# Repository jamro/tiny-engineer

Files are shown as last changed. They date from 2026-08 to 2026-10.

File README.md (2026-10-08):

# Tiny Engineer

> Give your AI coding agent a body.

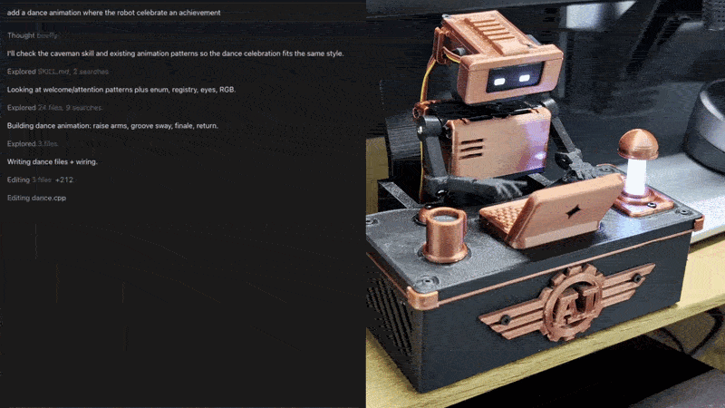
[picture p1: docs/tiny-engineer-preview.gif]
Tiny Engineer demo


**[Watch the demo](https://youtu.be/RX_QRxdXMjg)** · [Build your own](#build-your-own) · [Community builds](#community-builds) · [How it works](#how-it-works)

A small robot on your desk. It moves, changes its face, and rings a bell as your coding AI agent works.

| Your agent… | The robot… |
| --- | --- |
| Reads files | Looks around |
| Writes code | Types |
| Thinks or waits | Looks up |
| Finishes the task | Rings the bell |

Open source. Print the body, plug the ESP32, servos, OLED, and speaker into the [main control board](docs/hardware/main-control-board.md), flash it, and it joins your Wi-Fi.

**Works with** Claude Code · Cursor · Antigravity — via [`npx -y tiny-engineer setup`](docs/integration.md) — or Codex, Windsurf, and any script that can POST ([integration guide](docs/integration.md) · [HTTP API](docs/api.md)), including speech through [`POST /play`](docs/api.md#post-play).

## Build your own

| | |
| --- | --- |
| **Parts (electronics + 5× SG90 Servos)** | [shopping list](docs/shopping.md): [main control board](docs/hardware/order-main-control-board.md) plus ESP32, servos, OLED, and speaker |
| **Also needed** | 3D printer + filament, or [order prints](docs/3d/order-parts.md); M2 screws; **5 V / ≥2 A** USB supply |
| **Tools** | Plug in the ESP32, servos, OLED, and speaker on the [main control board](docs/hardware/main-control-board.md). Want to add extra modules? [advanced wiring](docs/hardware/wiring.md) |
| **Difficulty** | **Medium** - fair first hardware project for a software engineer, not a one-LED kit. Optional primer: [From Code to Circuits](docs/hardware-for-software-engineers/README.md) |

Main control board (https://github.com/jamro/tiny-engineer/discussions/50)

The default build uses the open-source main control board. Order it from any fab ([how to order](docs/hardware/order-main-control-board.md) · [KiCad](hardware/boards/main-control-board/)). 

If a ~$15–20 assembled board like this would be useful to you, [Vote here 👍 →](https://github.com/jamro/tiny-engineer/discussions/50) → I’m using the interest to decide whether it’s worth developing further.

**Print → Connect → Flash → Assemble** - step-by-step: **[Getting started](docs/getting-started.md)**.

## Community builds

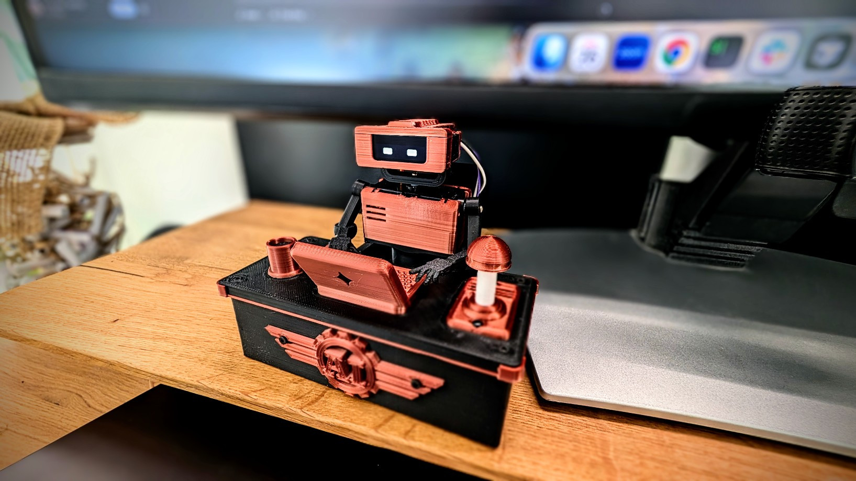
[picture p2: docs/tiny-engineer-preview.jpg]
Built Tiny Engineer


Finished builds, mods, and desk setups live in **[Show and tell](https://github.com/jamro/tiny-engineer/discussions/categories/show-and-tell)** on GitHub Discussions - browse what others made and post photos of yours.

**Built one? [Share in Show and tell →](https://github.com/jamro/tiny-engineer/discussions/categories/show-and-tell)**

## Roadmap

What we are building toward:

- **More agent integrations** - one-command hooks for more IDEs and CLIs
- **Simplified build process** - easier assembly and setup for quicker builds
- **New characters / bodies** - alternate shells and mods
- **Multi-agent desk** - more than one tiny teammate

**[Star Tiny Engineer](https://github.com/jamro/tiny-engineer)** to follow the build.

## How it works

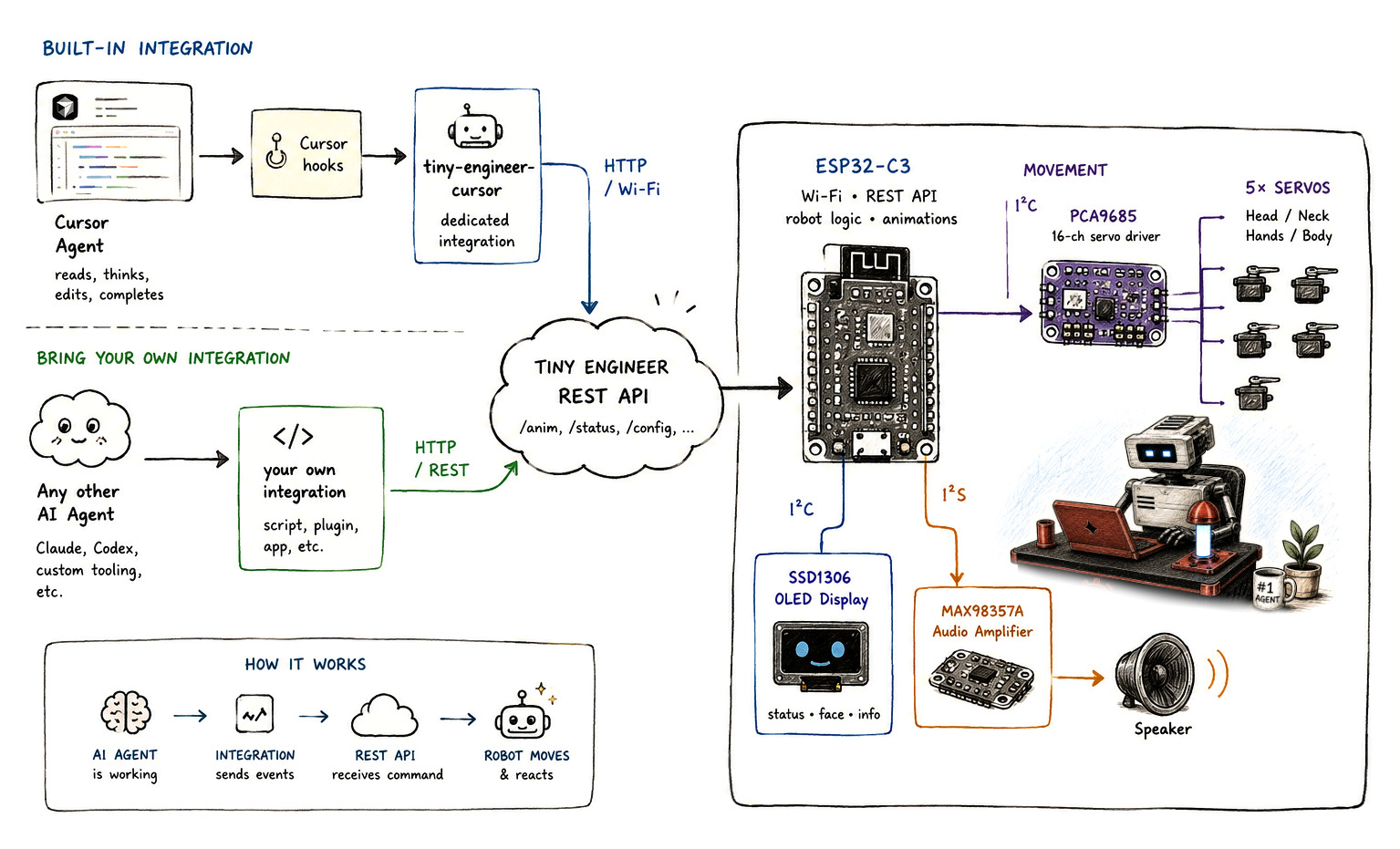
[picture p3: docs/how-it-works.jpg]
How Tiny Engineer works


Your agent (or a hook script) sends poses over HTTP. The **ESP32-C3** is a small Wi-Fi computer on the robot — one chip that runs the program, joins your network, hosts REST API, and drives the servos, the face, and the speaker.

**Clients**

- **Default** — [`npx -y tiny-engineer`](https://www.npmjs.com/package/tiny-engineer) (`setup` / `hook`) for Cursor, Claude Code, Antigravity → Wi-Fi
- **Advanced** — any tool that can `POST` to `/anim` ([HTTP API](docs/api.md))

Details: [Integrations](docs/integration.md) · [HTTP API](docs/api.md) · [Cursor hooks](docs/hooks.md)

## Documentation

| You want to… | Start here |
| --- | --- |
| Build the robot | [Getting started](docs/getting-started.md) |
| Buy parts | [Shopping list](docs/shopping.md) |
| Flash the board | **[Web flash](https://jamro.github.io/tiny-engineer/flash/)** · [Flash](docs/flash.md) |
| Assemble the prints | [Assembly](docs/3d/assembly.md) |
| Print the parts | [3D models](3d_models/README.md) |
| Hook up an agent | [Integrations](docs/integration.md) |
| Call the HTTP API | [API](docs/api.md) |
| Anything else | [Docs index](docs/README.md) |

Print it, connect it, change the CAD, or hook up another agent. Issues and PRs welcome - especially new integrations. [CONTRIBUTING.md](CONTRIBUTING.md) · [SECURITY.md](SECURITY.md) · [CODE_OF_CONDUCT.md](CODE_OF_CONDUCT.md)

## License

- **Software** (firmware, integrations, scripts, documentation) — [MIT](LICENSE)
- **Hardware designs** (CAD source and printables in [`3d_models/`](3d_models/) and under [`mods/*/3d_models/`](mods/); KiCad PCBs in [`hardware/`](hardware/)) — [CERN-OHL-S-2.0](3d_models/LICENSE)

See [LICENSING.md](LICENSING.md) for scope and effective date. The **Tiny Engineer** name and logo are not licensed - see [TRADEMARK.md](TRADEMARK.md).

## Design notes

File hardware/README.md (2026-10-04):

# Hardware (PCB)

KiCad PCB projects for Tiny Engineer. Builders: the main control board is the default electronics path — [shopping](../docs/shopping.md) and [connect guide](../docs/hardware/main-control-board.md). Breakout modules are an advanced path for extra hardware the board does not support — [wiring](../docs/hardware/wiring.md).

Boards live under `boards/<board-name>/`. Prefer the same name for the directory and the KiCad project.

| Board | Role |
| --- | --- |
| [`main-control-board`](boards/main-control-board/) | Main board: PCA9685, MAX98357A, and USB-C on the board; ESP32-C3-Zero plugs into two sockets |

Contribution rules, KiCad version, what to commit, ERC/DRC, and PR expectations: [docs/pcb.md](../docs/pcb.md). Pre-PR checklist: [docs/pcb.md#checklist](../docs/pcb.md#checklist). Critical net checklist: [docs/pcb.md#expected-netsyml](../docs/pcb.md#expected-netsyml). Local/CI checks: `python3 scripts/check_pcb.py` (KiCad 10) — [docs/testing.md](../docs/testing.md).

This tree is KiCad source only. Robot electrical reference (pinout, wiring, BOM) is [`docs/hardware/`](../docs/hardware/README.md). Firmware drivers are `src/hardware/`.

## License

Board sources in `boards/` are [CERN-OHL-S-2.0](LICENSE). See [NOTICE](NOTICE) for copyright, Source Location, and product notice requirements.

This README is software documentation and remains under the MIT License — [LICENSING.md](../LICENSING.md).

The **Tiny Engineer** name and logo are not licensed — [TRADEMARK.md](../TRADEMARK.md).

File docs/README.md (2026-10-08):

# Docs index

Pick a path. Depth lives in the linked pages.

### Building the robot

| You want to… | Start here |
| --- | --- |
| **Build from scratch** (canonical checklist) | [getting-started.md](getting-started.md) |
| **Buy parts** (main control board + cart) | [shopping.md](shopping.md) |
| **Bridge into hardware/electronics** (software engineer background) | [hardware-for-software-engineers/README.md](hardware-for-software-engineers/README.md) — optional parallel reading; safety card lives on the checklist |
| **Assemble printed parts** (mechanical procedure) | [3d/assembly.md](3d/assembly.md) |
| **Flash firmware** | **[Web flash](https://jamro.github.io/tiny-engineer/flash/)** (default) · [flash.md](flash.md) (PlatformIO / mods / OTA) |
| **Electronics** (main control board) | [shopping.md](shopping.md) → [hardware/main-control-board.md](hardware/main-control-board.md) → [hardware/README.md](hardware/README.md) |
| **Extra modules** (advanced breakouts) | [shopping.md](shopping.md#advanced-extra-modules) → [hardware/wiring.md](hardware/wiring.md) → [3d/assembly-modular.md](3d/assembly-modular.md) |
| **Print / parts inventory** | [../3d_models/README.md](../3d_models/README.md) |
| **Order printed parts** (no 3D printer) | [3d/order-parts.md](3d/order-parts.md) |
| **Order main control board** (PCB / PCBA) | [hardware/order-main-control-board.md](hardware/order-main-control-board.md) |
| **Adapt CAD to a different servo** | [3d/parametric-design.md](3d/parametric-design.md) |
| **Add a new CAD / printable part** | [3d/adding-parts.md](3d/adding-parts.md) |
| **Optional mods** | [../mods/README.md](../mods/README.md) |
| **Use with an agent** (robot already on Wi-Fi) | [integration.md](integration.md) (`tiny-engineer` CLI or REST) · Cursor: [hooks.md](hooks.md) |

### Reference and contribute

| You want to… | Start here |
| --- | --- |
| **Contribute a PCB** (KiCad) | [pcb.md](pcb.md) → [`hardware/`](../hardware/README.md) |
| **HTTP API / settings** | [api.md](api.md); add a setting: [settings.md](settings.md) |
| **CLI setup / REST for any IDE** | [integration.md](integration.md) |
| **Publish npm CLI** (`tiny-engineer`) | [cli-release.md](cli-release.md) |
| **Firmware / package tests** | [testing.md](testing.md) |
| **AI coding agents (repo rules)** | [AGENTS.md](../AGENTS.md) |
| **Contribute / report a vuln** | [CONTRIBUTING.md](../CONTRIBUTING.md); [SECURITY.md](../SECURITY.md) |
| **Share a finished build** | [Show and tell](https://github.com/jamro/tiny-engineer/discussions/categories/show-and-tell) — [how to post](../CONTRIBUTING.md#share-your-build) |

Also: [robot-movement.md](robot-movement.md) (servo axes and safe ranges); optional [macos-lock-unlock.md](macos-lock-unlock.md) (sleep/wake on Mac screen lock).

**Source of truth:** pin constants in firmware (`include/pins.h`); electrical detail in `docs/hardware/`; HTTP shapes in [api.md](api.md). Overall build order: [getting-started.md](getting-started.md).

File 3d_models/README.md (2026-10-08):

# 3D models

Printable parts and source CAD for the Tiny Engineer desk robot.

## Source CAD (edit / resize)

The full assembly — all components composed — lives in [`cad/TinyEngineer.f3d`](cad/TinyEngineer.f3d) (Autodesk Fusion). Open that file to adjust the model or adapt it to different hardware sizing (e.g. different servos). Parametric servo sizes and the Fusion add-in: [docs/3d/parametric-design.md](../docs/3d/parametric-design.md).

**Adding a new part** (parametric rules, timeline, `PRINT_LAYOUT`, Servo Configurator, export, optional mods): [docs/3d/adding-parts.md](../docs/3d/adding-parts.md). Optional / community mods: [`mods/`](../mods/).

## Printables

Individual parts are exported under [`parts/{servo_id}/`](parts/). Match the folder to the servos you bought ([which servo](../docs/shopping.md)). `stl/` next to `3mf/` is the same mesh in binary STL. `step/` next to those is CAD interchange (BRep STEP), not a printable mesh for a home slicer.

Two ways to get the mechanical set (same place in the build path):

- **Print yourself** — use the **`.3mf` files in `parts/sg90/3mf/`**, **`parts/fs0307/3mf/`**, **`parts/es9051/3mf/`**, or **`parts/hd1370a/3mf/`**. Ready to print in an orientation that does not need supports. **PLA** or **PETG**. Start with [Print first](#print-first).
- **No printer?** — order the aggregated sets from a third-party service: [order printed parts](../docs/3d/order-parts.md). Orders are at your own risk; fit can vary by provider and design revision.

### Print first

**Home printers only.** Print these two small testers from that folder **before** the rest of the set. Do not print the full robot until both fit. Skip this step when ordering from a service (testers alone are rarely worth the min fee + shipping).

1. **`ServoSizingTester.3mf`** — seat a real servo; do not force it. The body should slide, tabs sit, holes line up, and the shaft should have clearance. Tight or loose → sand/ream, or adjust servo CAD params ([parametric design](../docs/3d/parametric-design.md)).
2. **`ScrewSizingTest.3mf`** — M2 screw pilot-hole tolerance. Each hole is marked with its diameter. Drive an M2 screw into each hole and pick the tightest size that still cuts a thread (does not spin freely / slide through). Set Fusion user parameter `screw_thread_diameter` to that marked value, then re-export before printing structural parts. Details: [M2 screw holes](../docs/3d/parametric-design.md#m2-screw-holes).

Assembly uses **M2 screws** that thread directly into the printed PLA/PETG — no glue, no heat-set inserts. Easy to dismount and modify later. Buyer cart (electronics + screw qty + supply): [docs/shopping.md](../docs/shopping.md). Overall build order: [docs/getting-started.md](../docs/getting-started.md). Mechanical procedure: [docs/3d/assembly.md](../docs/3d/assembly.md). Per-step lengths: [screw list](#screws) below.

### Screws

**Spec:** M2 thread-forming (self-tapping) screws for plastic, **pan-head or button-head** — heads normally sit on the plastic surface. `BottomCover` has recessed head pockets; use heads no larger than **4.0 mm diameter × 2.0 mm high** so the underside rests flat. CAD default pilot is **2.1 mm** (Fusion user parameter `screw_thread_diameter`); if your `ScrewSizingTest` winner differs, re-export at that diameter before printing structural parts. Details: [M2 screw holes](../docs/3d/parametric-design.md#m2-screw-holes).

**One BOM for every servo preset** (`parts/sg90/`, `parts/fs0307/`, `parts/es9051/`, `parts/hd1370a/`, …). Printed parts scale with the servo choice, but the lengths below are the reference list for all of them — including smaller models for smaller servos. Buy quantities: [docs/shopping.md](../docs/shopping.md). Pilots are cut as deep as practical so nearby lengths often work too; if you already have different M2 lengths, test-fit before buying a full set. Per-step placement: [assembly guide](../docs/3d/assembly.md).

**Per robot (qty is source of truth):**

| Item | Qty | Typical use |
| --- | --- | --- |
| M2×4 mm | 8 | Emblem, PCA9685, MAX98357A |
| M2×8 mm | 27 | Hat, Neck↔Head, Chest center (prefer two), Belly↔Chest, LampBase, laptop, mug, Chair↔Desk, elbows, BottomCover ×6 |
| M2×16 mm | 15 | Chest side servos, SeatLeft/Right, DeskTop stack, USB-C, Bell |
| M2 nuts | 6 | Neck captured ×1, USB-C ×4, Bell ×1 |
| Servo bag screws | 5 | Neck shaft, Neck↔Head (robot’s left), Belly shaft, both arms |

Prefer **two** M2×8 for the Neck servo in `Chest`; one at the back is enough if space is tight (buy 27 either way). An M2 assortment covering **M2×4–M2×16** is the easy path.

## Parts

Same filenames in each `parts/{servo_id}/3mf/` folder (and matching `stl/` / `step/`):

| File | Role |
| --- | --- |
| `PartsSetA.3mf` | Aggregated copper-color group for [service orders](../docs/3d/order-parts.md) (home print: use individuals below) |
| `PartsSetB.3mf` | Aggregated black-color group for [service orders](../docs/3d/order-parts.md) (home print: use individuals below) |
| `Head.3mf` | Head (pitch) |
| `Neck.3mf` | Neck (yaw) |
| `ForearmLeft.3mf` | Left forearm / hand |
| `ForearmRight.3mf` | Right forearm / hand |
| `UpperArm.3mf` | Upper arm |
| `Chest.3mf` | Chest / torso |
| `Belly.3mf` | Belly |
| `Chair.3mf` | Chair |
| `SeatLeft.3mf` | Left chair seat |
| `SeatRight.3mf` | Right chair seat |
| `Desk.3mf` | Desk structure |
| `BottomCover.3mf` | Underside cover; six M2×8 (four desk, two chair) |
| `DeskTop.3mf` | Desk top surface |
| `DeskPad.3mf` | Desk pad |
| `LaptopCase.3mf` | Miniature laptop body |
| `LaptopScreen.3mf` | Laptop screen |
| `Bell.3mf` | Service bell |
| `LampBase.3mf` | Desk lamp base |
| `LampCap.3mf` | Lamp cap |
| `LampDiffuser.3mf` | Lamp diffuser |
| `LampButton.3mf` | Lamp button |
| `Mug.3mf` | Mug |
| `Coffee.3mf` | Coffee fill |
| `Hat.3mf` | Hat |
| `ServoSizingTester.3mf` | Servo pocket fit tester |
| `ScrewSizingTest.3mf` | M2 screw pilot-hole diameter tester |
| `AiEmblem.3mf` | AI emblem detail |

## Next steps

Return to the build checklist: [docs/getting-started.md](../docs/getting-started.md) ([§2 Print or order](../docs/getting-started.md#2-print-or-order) done). Connect and flash **before** opening the mechanical guide.

1. Connect, then flash: [docs/hardware/main-control-board.md](../docs/hardware/main-control-board.md), [docs/flash.md](../docs/flash.md). Extra modules: [docs/hardware/wiring.md](../docs/hardware/wiring.md)
2. Assemble in one run: [docs/3d/assembly.md](../docs/3d/assembly.md)
3. Servo axes and safe ranges: [docs/robot-movement.md](../docs/robot-movement.md)
4. Bring-up and failures: [docs/hardware/testing.md](../docs/hardware/testing.md)

## License

CAD source (`.f3d`) in [`cad/`](cad/) and printable parts (`.3mf`) in [`parts/`](parts/) are licensed under [CERN-OHL-S-2.0](LICENSE). See [NOTICE](NOTICE) for copyright, Source Location, and product notice requirements.

Commercial use is allowed. If you modify and distribute Products based on these designs, reciprocal provisions require sharing your Complete Source under the same license. This documentation file is software documentation and remains under the MIT License — see [LICENSING.md](../LICENSING.md).

The **Tiny Engineer** name and logo are not licensed — see [TRADEMARK.md](../TRADEMARK.md).

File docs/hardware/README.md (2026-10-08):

# Tiny Engineer — hardware overview

Canonical hardware reference for the Tiny Engineer robot.

Firmware pin constants live in [`include/pins.h`](../../include/pins.h). The default build is the **main control board** ([main-control-board.md](main-control-board.md)). The advanced path wires separate breakouts ([wiring.md](wiring.md) + drawio) when you add modules the board does not support. Same nets and firmware.

Source of truth: firmware `include/pins.h`, then this `docs/hardware/` set. Modular topology: `docs/wiring/`. PCB connectivity: board `expected-nets.yml` / netlist per [pcb.md](../pcb.md).

| Audience | Use this set for |
| --- | --- |
| Human | Assembly, wiring, power, bring-up, debugging |
| Firmware agent | Pin map, buses, voltages, servo PWM conventions, test sequence |

## Purpose

Small desktop robot with:

- 5 analog micro servos (head, neck, hands, body — [robot-movement.md](../robot-movement.md))
- I2C OLED status display
- I2S speaker for tones and WAV playback
- ESP32-C3 Wi-Fi for HTTP control and AI hooks

Firmware (`src/main.cpp`) is the robot application: Wi-Fi, settings, hardware tests, animations, and the JSON API.

## Hardware architecture

One ESP32-C3 module owns all logic. Servo PWM is offloaded to a PCA9685 so pulse generation does not depend on ESP32 timing. Audio is I2S into a class-D amp. Display and servo driver share one I2C bus. On the default build those chips are on the main control board. The advanced path puts the same chips on breakouts — the diagram is the same either way.

```mermaid
flowchart TB
  USB["USB 5V / GND<br/>as drawn"]

  subgraph p5["5 V power domain"]
    ESP5["ESP32 5V"]
    PCA5["PCA9685 5V"]
    PCAVplus["PCA9685 V+"]
    MAXVIN["MAX98357A Vin"]
    SERVOS["Servo 5V"]
  end

  subgraph p33["3.3 V logic domain"]
    ESP["ESP32-C3-Zero"]
    PCA["PCA9685 VCC"]
    OLED["OLED VCC"]
  end

  USB -->|"5V"| ESP5
  USB -->|"5V"| PCA5
  USB -->|"5V"| MAXVIN
  PCA5 --> PCAVplus
  PCAVplus --> SERVOS
  ESP5 --> ESP
  ESP -->|"3V3"| PCA
  ESP -->|"3V3"| OLED
  ESP -->|"GP0 SDA / GP1 SCL"| PCA
  ESP -->|"GP0 SDA / GP1 SCL"| OLED
  ESP -->|"GP2 BCLK / GP3 LRC / GP4 DIN"| MAXVIN
  PCA -->|"PWM"| SERVOS
```

Speaker **SPK+/SPK-**: [main-control-board.md](main-control-board.md). The modular PNG omits them — [wiring.md](wiring.md#not-on-the-drawing).

| Domain | Voltage | What lives there |
| --- | --- | --- |
| Power rail | **+5V** | USB **5V** → ESP32 **5V**, PCA9685 **5V**, MAX98357A **Vin**; PCA9685 **V+** → servo **5V** |
| Logic | **3V3** | ESP32 GPIO, PCA9685 **VCC**, OLED **VCC**, I2C, I2S |
| Ground | **GND** | Every module — common ground is mandatory |

> [!WARNING]
> Never power the servos from the ESP32 3.3 V regulator.

> [!WARNING]
> MAX98357A SPK- is not ground. Speaker connects between SPK+ and SPK- only.

## Major components

| Role | Main control board (default) | Advanced breakouts | Qty |
| --- | --- | --- | --- |
| Controller | Waveshare ESP32-C3-Zero (plugs into board sockets) | same | 1 |
| Servo PWM | PCA9685 on PCB | Adafruit PCA9685 breakout | 1 |
| Actuators | Analog micro servos — **Tower Pro SG90 recommended**; Feetech FS0307 / EMAX ES9051 compact; PowerHD HD-1370A still supported | same | 5 |
| Audio amp | MAX98357A on PCB | MAX98357A breakout | 1 |
| Speaker | [Adafruit Mini Oval Speaker - 8 Ohm 1 Watt](https://www.adafruit.com/product/3923) | same | 1 |
| Display | [Waveshare 0.91inch OLED Module](https://www.waveshare.com/0.91inch-oled-module.htm) (SSD1306, 128×32, I2C) | same | 1 |
| Robot USB | USB-C on PCB | Adafruit 5993 USB-C breakout | 1 |

Carts: [shopping.md](../shopping.md). Spec detail: [components.md](components.md). Connect: [main-control-board.md](main-control-board.md).

## Communication buses

| Bus | ESP32 pins | Devices |
| --- | --- | --- |
| I2C | GP0/SDA, GP1/SCL (Waveshare OLED **SCL**) | PCA9685 `0x40`, SSD1306 `0x3C` |
| I2S | GP2/BCLK, GP3/LRC, GP4/DIN | MAX98357A |
| Servo PWM | *(none on ESP32)* | PCA9685 channels 0–4 @ 50 Hz |
| USB | Board USB-C (VBUS/GND + D+/D− → GP19/GP18). Advanced path: 5993 — [wiring.md](wiring.md) | Power, flash, serial CDC |

Details: [interfaces.md](interfaces.md), [pinout.md](pinout.md).

## Power architecture

Single nominal **+5V** supply via the main control board USB-C. ESP32 onboard LDO makes **3V3** for logic only. PCA9685 **V+** (servos) is electrically separate from PCA9685 **VCC** (logic). The advanced path brings 5 V in through an Adafruit 5993 — [wiring.md](wiring.md).

Prefer a **5 V / ≥2 A** source with margin. Details: [power.md](power.md).

## Documentation map

| File | Contents |
| --- | --- |
| [../shopping.md](../shopping.md) | Default cart; advanced extra modules |
| [main-control-board.md](main-control-board.md) | Default connect: ESP32, OLED, servos, speaker |
| [order-main-control-board.md](order-main-control-board.md) | Order the PCB / PCBA (any fab; JLCPCB walkthrough) |
| [components.md](components.md) | Inventory, voltages, limits |
| [pinout.md](pinout.md) | GPIO map + allocation rules |
| [wiring.md](wiring.md) | Advanced: breakout harness |
| [../3d/assembly-modular.md](../3d/assembly-modular.md) | Advanced: mount breakouts in the desk |
| [power.md](power.md) | Budget, brownout symptoms, single-USB policy |
| [servos.md](servos.md) | PWM, test limits, safe ranges |
| [interfaces.md](interfaces.md) | I2C / I2S / PWM / USB |
| [testing.md](testing.md) | Bring-up sequence, failures, what to check |

Modular schematic sketch: [`docs/wiring/Tiny Engineer.drawio`](../wiring/Tiny%20Engineer.drawio) / [PNG](../wiring/Tiny%20Engineer.drawio.png). KiCad: [`hardware/boards/`](../../hardware/README.md); contribution rules: [`docs/pcb.md`](../pcb.md).

## Source-of-truth order

1. Repository firmware / `include/pins.h`
2. This `docs/hardware/` set; modular nets also in `docs/wiring/`; PCB nets via board expected-nets / netlist
3. Component datasheets

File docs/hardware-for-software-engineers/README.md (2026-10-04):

# From Code to Circuits: Hardware for Software Engineers

*Learn electronics and physical builds through Tiny Engineer — a desk robot that's fun to finish and honest about real hardware.*

I wrote this because software engineers keep asking how to build Tiny Engineer when they've never touched the hardware side — what's a servo driver, why two voltages, whether they'll destroy the board on first power-on. The build docs tell you *what to connect*; this guide answers the questions behind them.

---

## Goal

**Bring the world of electronics and hardware closer to software engineers** — especially the ones showing up with Tiny Engineer parts and no hardware background.

If you live in code, hardware docs can feel like a foreign API with no types and no stack traces. This guide closes that gap: same systems thinking you already use — buses, power budgets, failure modes — applied to volts, GPIO, and printed plastic. It's the long-form version of answers I give when someone says *"I'm a developer, I just want the robot to work."*

**Why now:** AI makes writing code fast and cheap. Hardware stays tangible, constrained, and extremely satisfying when something on your desk actually moves because *you* wired it.

**Why Tiny Engineer as the example:** one coherent stack (MCU, I2C, I2S, power domains, 3D print, servos) — real enough to teach honest hardware, bounded enough to finish if you stick with it. It also ties back to software via Wi-Fi and HTTP, which helps the mental bridge.

**What you'll get out of it:** read datasheets, schematics, and embedded docs without feeling like an outsider — whether you build this robot or the next board on your bench.

**Honest expectation:** Tiny Engineer was never meant to be an entry-level electronics kit (no single-LED breadboard tutorial). Overall difficulty is **medium**. It can still be your **first hardware project** as a software engineer — if you read alongside the build, smoke-test the main control board on the desk (connect + flash) before closing the shell, and don't treat "first" as "trivial." Harness examples later in this guide are the advanced path for extra modules — [wiring.md](../hardware/wiring.md). See [difficulty by area](#honest-difficulty-by-area) below.

---

I'm a software engineer. I got into hardware and electronics long before Tiny Engineer — out of curiosity, because I find it fun, and because making something *physical* work hits different from shipping another service. I'm not an EE. I've smelled the regret breadboard too; I've also had plenty of projects since then that actually moved and blinked.

Tiny Engineer is one project in that line. I'd recommend this path to any software engineer: learn the basics, wire something on a bench, watch it do a thing you commanded. Especially now, when a servo buzzes because you misaligned a horn — not because a model hallucinated a pin number — you learn something no codegen session replaces.

**What this is:** a bridge into electronics, microcontrollers, power, protocols, and mechanical build craft — taught with software-engineer mental models.

**What this is not:** only a Tiny Engineer assembly manual. When you're ready to build step by step, use [getting-started.md](../getting-started.md) (checklist), [flash.md](../flash.md), and the [hardware reference](../hardware/README.md).

---

## Why Tiny Engineer is the example

Every chapter teaches a **general concept**, then shows **where it lands in this build**. Tiny Engineer gives you real constraints — 3.3 V vs 5 V domains, shared I2C, offloaded servo PWM, print tolerances, antenna keep-out — without throwing you into a parts warehouse with no narrative. Finish the robot if you want the payoff; the vocabulary transfers to other ESP32, Arduino, or IoT projects either way.

It's a good **first hardware project for a software engineer**. It is **not** a good **first project in electronics** in the abstract — compare it to a blinking-LED kit and this is several notches up. This guide exists because those two truths collide constantly in questions from SWEs who want to build the robot anyway.

---

## Honest difficulty by area

Rough levels: **Easy** · **Medium** · **Medium–High** (for someone with no prior hardware builds). Overall build: **Medium**.

| Area | Level | Why |
| --- | --- | --- |
| [Electricity & power domains](01-electricity-and-units.md) | Medium | Two voltage rails, common GND, VCC vs V+ — mistakes fry boards, not just fail tests |
| [Microcontrollers & ESP32](02-microcontrollers-and-esp32.md) | Medium | Wi-Fi MCU, native USB, scarce GPIO, flash/LittleFS — more moving parts than Arduino Uno 101 |
| [Wiring & schematics](03-wiring-craft-and-schematics.md) | Medium–High | Default board is plug-in. The advanced harness is six-ish modules, many nets, classic traps (swapped I2C, speaker on GND) |
| [Buses: I2C, I2S, PWM](04-buses-and-protocols.md) | Medium | Three protocol types in one device; standard hobby stack, but not "one wire one LED" |
| [Servos & mechanical motion](05-servos-and-mechanical-motion.md) | Medium–High | Five joints, horn alignment, mechanical limits, binding/stall — software clamps can't fix physics |
| [3D printing & mechanical build](06-3d-printing-and-mechanical-build.md) | Medium | Many printed parts, tolerances, partial assembly docs; optional Fusion edits add learning curve |
| [Power budgets & safety](07-power-budgets-and-safety.md) | Medium | Real stall currents (~1.3–1.6 A), supply sizing, brownout debugging |
| [Embedded workflow & debug](08-tools-debugging-and-embedded-workflow.md) | Medium *(lower if you live in CLI)* | PlatformIO, serial, bisect bring-up — familiar shape for SWEs, unfamiliar failure modes |
| REST / Wi-Fi / agent hooks | Easy *(for SWEs)* | HTTP you already know — **after** hardware works |

**What makes it medium, not beginner-kit:**
- Multiple ICs on shared buses, not one chip
- Motor power + logic power discipline
- Mechanical assembly with real tolerances
- Debug requires dividing hardware vs software

**What makes it viable as a first SWE hardware project:**
- Documented BOM, wiring, firmware — not a blank breadboard
- Software-shaped affordances: serial logs, HTTP `/test/*`, web UI
- This guide translates concepts into your vocabulary first
- Finish line is motivating (desk robot, not only a blinking LED)

If you've never touched a multimeter, budget extra time on [Ch. 01](01-electricity-and-units.md), [Ch. 07](07-power-budgets-and-safety.md), and bring-up discipline in [Ch. 08](08-tools-debugging-and-embedded-workflow.md). Skipping straight to "assemble everything and flash" (or closing the chest before desk smoke) is how medium projects feel hard.

---

## Who should read this

**Read this if you:**
- Write code for a living and want to build Tiny Engineer (or similar) without a hardware background
- Got the parts or the repo and hit questions the assembly docs don't pause to explain
- Know what HTTP is but not what I2C is
- Can follow a tutorial but want to understand what you're doing
- Are curious about embedded, IoT, or physical computing — even if you've never soldered

**Skip this if you:**
- Already own a multimeter and use words like "pull-up" without Googling
- Have built an ESP32 project before and just need the BOM — go to [shopping.md](../shopping.md) and [getting-started.md](../getting-started.md)

**Don't skip the difficulty section** if this is your first hardware build — [Honest difficulty by area](#honest-difficulty-by-area) sets expectations.

---

## How this fits the rest of the docs

There are three layers. Read them in order when you're learning; jump to the right layer when you know what you need.

```mermaid
flowchart LR
  primer["hardware-for-software-engineers\n(concepts)"]
  build["getting-started.md\n(checklist)"]
  ref["hardware/\n(reference)"]

  primer -->|"understand why"| build
  build -->|"look up details"| ref
```

| Layer | When to use it |
| --- | --- |
| **This guide** | Bridging hardware/electronics concepts from a software background |
| **[getting-started.md](../getting-started.md)** | Canonical build checklist (open leaf docs, return) |
| **[hardware/](../hardware/README.md)** / [flash.md](../flash.md) | Looking up pins, wiring, power, flash, test procedures |

---

## Reading order

**Alongside the checklist** if hardware is new — print while you read; do not finish this guide before [getting-started.md](../getting-started.md):

1. [Electricity and units](01-electricity-and-units.md)
2. [Microcontrollers and ESP32](02-microcontrollers-and-esp32.md)
3. [Wiring craft and schematics](03-wiring-craft-and-schematics.md)
4. [Buses and protocols](04-buses-and-protocols.md)
5. [Servos and mechanical motion](05-servos-and-mechanical-motion.md)
6. [3D printing and mechanical build](06-3d-printing-and-mechanical-build.md)
7. [Power budgets and safety](07-power-budgets-and-safety.md)
8. [Tools, debugging, and embedded workflow](08-tools-debugging-and-embedded-workflow.md)
9. [How it all fits together](09-how-it-all-fits-together.md)

**Shortcuts** — where universal concepts land in this build; jump to one chapter if you only need that topic:

| You need to understand… | Read |
| --- | --- |
| ESP32-C3-Zero, GPIO, USB, antenna | [Ch. 02](02-microcontrollers-and-esp32.md) |
| 3.3 V vs 5 V, LDO, VCC vs V+ | [Ch. 01](01-electricity-and-units.md) + [Ch. 07](07-power-budgets-and-safety.md) |
| I2C (OLED + PCA9685) | [Ch. 04](04-buses-and-protocols.md) |
| I2S (audio) | [Ch. 04](04-buses-and-protocols.md) |
| Servo PWM chain | [Ch. 04](04-buses-and-protocols.md) + [Ch. 05](05-servos-and-mechanical-motion.md) |
| Fusion CAD edits | [Ch. 06](06-3d-printing-and-mechanical-build.md) |
| PLA vs PETG | [Ch. 06](06-3d-printing-and-mechanical-build.md) |

---

## Mini glossary

Terms you'll see everywhere. Each chapter goes deeper. Think of these as hardware concepts translated into software-shaped words.

| Term | One-line meaning |
| --- | --- |
| **MCU** | The chip that runs your firmware — like a tiny server that boots straight into one binary (no OS, no SSH). Here: ESP32-C3 |
| **GPIO** | A pin the firmware can drive or read — hardware I/O endpoints, not USB or Wi-Fi |
| **GND** | Shared **0 V reference** for every module — like agreeing on one clock/time base; without it, nothing can talk reliably |
| **3.3 V / 5 V** | **Signal voltage** (3.3 V, ESP32-safe) vs **power rail** (5 V, servos/amp) — two different numbers; don't mix them up |
| **LDO** | Onboard **5 V → 3.3 V converter** for logic chips — sized for milliamps, not motors |
| **I2C** | Two-wire **request/response bus** — each chip has an address (`0x40`, `0x3C`); ESP32 is the only master |
| **I2S** | **Streaming audio bus** — continuous PCM samples over wires, like a one-way socket, not I2C-style reads |
| **PWM** | A pin toggling on/off on a schedule — servos read **pulse length** inside each cycle as "go to this angle" |
| **Brownout** | Power sags → chip **hard-resets** — feels like a random reboot, often when servos or audio spike current |
| **PCA9685** | **Servo PWM co-processor** — ESP32 sends angles over I2C; this chip generates the precise 50 Hz pulses |

---

## When you're ready to build

You've read enough when you can explain in plain language:

- Why servos don't get power from the ESP32's 3.3 V pin
- What I2C and I2S do on this robot (and that they're different)
- Why there's a separate PCA9685 chip instead of "just PWM in code"
- Where the ceramic antenna is and why you shouldn't bury it in plastic

**Minimum skim before power:** [Ch. 01](01-electricity-and-units.md) and [Ch. 07](07-power-budgets-and-safety.md) (3.3 V vs 5 V, VCC ≠ V+). This guide is **parallel reading**, not a prerequisite. Jump to one chapter from the shortcuts table if you only need that topic.

Then open [getting-started.md](../getting-started.md) and work the checklist (shop → print → connect → flash → assemble → wizard → prove).

**Reference:** [getting-started.md](../getting-started.md) · [hardware/README.md](../hardware/README.md) · [3d_models/README.md](../../3d_models/README.md)

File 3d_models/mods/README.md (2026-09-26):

# Mods

Optional and community CAD mods for Tiny Engineer. Not stock robot parts — those live in [`cad/`](../cad/) and [`parts/`](../parts/).

## Layout

```text
mods/<mod_name>/
  cad/       # Fusion source
  parts/     # Exported meshes (mirror 3d_models/parts/)
  README.md  # recommended: fit notes, which servo folders exported
```

## Workflow

Design, timeline, `PRINT_LAYOUT`, export, and checklist: [docs/3d/adding-parts.md](../../docs/3d/adding-parts.md).

## License

Same as parent [`3d_models/`](../) — [CERN-OHL-S-2.0](../LICENSE). See [NOTICE](../NOTICE).

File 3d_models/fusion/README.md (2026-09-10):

# Fusion add-in

Add-in code lives in [`TinyEngineerTools/`](TinyEngineerTools/). Folder name, `TinyEngineerTools.py`, and `TinyEngineerTools.manifest` must stay the same.

Install, servo parameters, configurator, and export: [docs/3d/parametric-design.md](../../docs/3d/parametric-design.md).

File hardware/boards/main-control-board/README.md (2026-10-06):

# main-control-board

This board drives the robot's servos and speaker. Power and USB data come in on a USB-C connector. The Waveshare ESP32-C3-Zero is not soldered down; it plugs into two 9-pin sockets.

- **Status:** draft (schematic and routed layout)
- **KiCad:** 10
- **Built:** not manufactured
- **Tested:** not tested

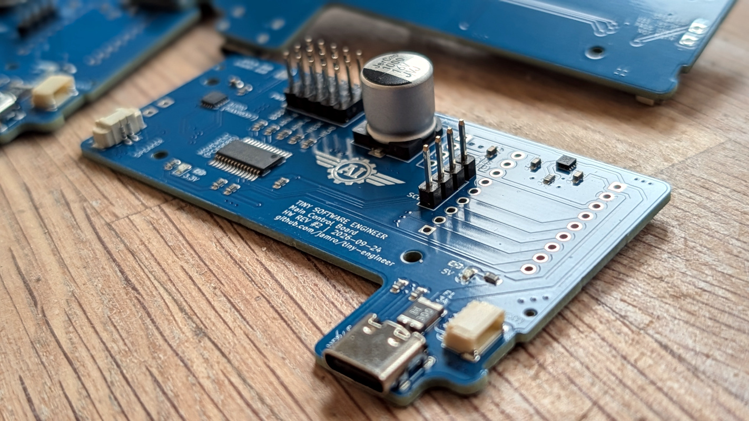
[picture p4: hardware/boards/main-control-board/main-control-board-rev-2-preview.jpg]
Main Control Board


## Soldered on the board

The servo driver, the speaker amplifier, and the USB-C connector are parts on this PCB. They replace the plug-in PCA9685 board, the MAX98357A breakout, and the Adafruit 5993 USB-C breakout.

- **PCA9685** drives up to 16 PWM channels. This robot uses five of them for the servos. The I2C address is `0x40`: the address pins and the external-clock pin are tied to ground, so the chip uses its own clock.
- **Servo header** takes five servo plugs. Each plug has ground, 5 V, and a PWM signal.
- **MAX98357A** is the mono class-D amplifier. The speaker connects to a 2-pin header. The speaker's minus terminal is not ground. Connect the speaker only between the two amplifier outputs.
- **USB-C connector** supplies 5 V and the USB data pair. Two 5.1 kΩ resistors on the CC pins mark this board as a USB device. The charger decides how much current is available.
- A **3 A resettable fuse** sits between USB power and the 5 V rail.
- A **TPS259571** eFuse (`U4`) sits between that 5 V rail and servo 5 V. Current limit is set by `R14` (1 kΩ ≈ 2 A). On fault the device auto-retries.
- **OLED header** is for the SSD1306 display. Pin order, from pin 1: 3.3 V, ground, SDA, SCL.
- A second header shares that I2C bus. Its pin order is different: ground, 3.3 V, SDA, SCL.
- A **12-pin extension port** (`J4`) breaks out `SERVO_5V`, two grounds, `+3.3V`, I2S BCLK/LRC, and GPIOs GP6–GP9 / GP20 / GP21.
  - GP8 and GP9 are ESP32-C3 strapping pins. Do not pull them low at reset; GP9 low enters download mode.
  - GP20 and GP21 are the default UART0 RX/TX. Boot log output appears on GP21 at power-up.

A solder jumper next to the amplifier is marked as a 6 dB gain limit.

## What still plugs in

The **Waveshare ESP32-C3-Zero** plugs into two 9-pin sockets, one for each row of pins on the module. This board has no ESP32 chip of its own.

The OLED module plugs into the OLED header.

## Power

USB-C 5 V goes through the fuse onto the `+5V` rail. That rail feeds the ESP32 5 V pin, a 5 V indicator LED, and the eFuse input.

The eFuse output is `SERVO_5V`. That rail feeds the servo plugs (PCA9685 V+), a bulk capacitor, and — through a net tie — the amplifier 5 V net, so the amp supply can still be routed on its own but comes from the protected servo rail, not raw `+5V`.

3.3 V comes from the regulator on the ESP32 module. This board does not have a 3.3 V regulator. 3.3 V feeds the PCA9685 logic supply, the OLED, the I2C pull-ups (4.7 kΩ), the pull-up on the PCA9685 output-enable pin (10 kΩ), and a 3.3 V indicator LED.

Servo 5 V and logic 3.3 V stay separate. They share ground.

Use a **5 V supply of at least 2 A**. Five stalled servos can draw more than a typical USB port provides. Multi-servo stall can also hit the eFuse’s ~2 A limit before the 3 A resettable fuse trips.

## Connections from the ESP32

| Function | ESP32 pin | Goes to |
| --- | --- | --- |
| I2C SDA | GP0 | PCA9685 and OLED |
| I2C SCL | GP1 | PCA9685 and OLED |
| I2S bit clock | GP2 | MAX98357A BCLK |
| I2S word clock | GP3 | MAX98357A LRC |
| I2S data | GP4 | MAX98357A DIN |
| Servo output enable | GP5 | PCA9685 output enable (active low) |
| USB D− | GPIO18 | USB-C |
| USB D+ | GPIO19 | USB-C |

GP5 drives PCA9685 OE (`PCA9685_OE_WIRED` in [`include/pins.h`](../../../include/pins.h)). A 10 kΩ pull-up holds OE high until firmware drives it low after neutral park.

## Board

Two-layer FR4, about 1.6 mm thick.

5 V tracks (`+5V` and `SERVO_5V`) are 1.5 mm wide. 3.3 V tracks are 0.4 mm. The amplifier 5 V net is 0.5 mm. USB data tracks use their own width.

The two ESP32 sockets follow the Waveshare header. Pad 1 is 5 V. Pads count anticlockwise from the module's USB connector. Those numbers are the module's header pads, not the pins of the ESP32-C3 chip.

## Library exceptions

### USB1 3D model (C2765186)

Footprint `USB-C-SMD_TYPE-C-16PIN-2MD-073` loads `USB-C-SMD_TYPE-C-6PIN-2MD-073.{wrl,step}`.

EasyEDA has no separate `…16PIN….wrl` for this LCSC part. Official package `c_para.3DModel` is `USB-C-SMD_TYPE-C-6PIN-2MD-073` (outline3D uuid `4ee8413127e64716b804db03d4b340ae`). Re-import via `import_lcsc.py --lcsc-id C2765186` reproduces the same mapping.

Do not rename or replace the model only to silence filename-mismatch reviews — this is intentional.

Contribution rules: [`docs/pcb.md`](../../../docs/pcb.md).

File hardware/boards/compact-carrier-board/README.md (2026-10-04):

# compact-carrier-board

Small distribution PCB that sits under the ESP32-C3-Zero where it mounts through
the desk's ESP slot, fanning its I2C/I2S/power pins out to the PCA9685, OLED,
MAX98357A amp, and servo power — instead of point-to-point wiring.

- **Status:** in review
- **KiCad:** 10
- **Interfaces:** ESP32-C3-Zero 2×9 socket, `J_PWR` (5V/GND + external USB
  D+/D-), `J_SERVO`, `J_I2C_OLED`, `J_I2C_PCA`, `J_I2S`
- **Assumptions:** sized against the desk generated with the **PowerHD
  HD-1370A** servo preset (`servos.json`) — the SG90 and FS0307 presets
  produce different desk dimensions per the parametric design docs, and this
  board's fit has **not** been verified against either of them. Re-check the
  ESP slot dimensions in your own exported desk model before relying on this
  outline if you're on a different preset. See `docs/hardware/interfaces.md`
  for the canonical net map (5V/3.3V domains, GP0-GP4 assignments); this
  board implements that map in copper.
- **Built:** the `carrier-fab-v3-replacement_Y5` upload was produced and
  shipped by JLCPCB (not yet received). That batch carries the **mirrored
  socket map this revision fixes** — see "Mirrored socket map (boards in
  transit)" below for the assembly workaround. Its drilling is fine: the Y5
  drill export is a single 0.9mm tool over all 37 holes and JLC's own CAM
  layer a single aperture, so the 7-undersized-hole defect of the earlier
  `_Y3` upload never reached a physical board.

## Files

- `compact-carrier-board.kicad_pcb` — KiCad 10 board source
- `compact-carrier-board.kicad_pro` — KiCad 10 project file (no `.kicad_sch`
  — this board has no schematic, laid out directly from footprints)
- `carrier-board-render.png` — 3D top render, regenerated with
  `kicad-cli pcb render --side top` after the row swap and silk additions

Gerbers, drill, BOM, and CPL are generated outputs, not source — regenerate
them from `compact-carrier-board.kicad_pcb` when ordering rather than
relying on a committed copy. `J_ESP1`/`J_ESP2` carry real `Value`/`LCSC`
fields and each footprint has a real origin at its own center, so
`kicad-cli pcb export pos` produces correct positions directly (verified:
`(13.00, -16.89)` / `(13.00, -1.65)`) — no manual patching. `J_PWR`,
`J_SERVO`, `J_I2C_OLED`, `J_I2C_PCA`, and `J_I2S` are flagged
`exclude_from_bom`/`exclude_from_pos_files` so they never appear in either
export. There's no `.kicad_sch`, so `kicad-cli` has no BOM-export
subcommand for this board (that's a schematic-only feature) — a BOM script
or fab-tool plugin reading the `.kicad_pcb`'s footprint properties directly
now gets correct `Value`/`LCSC` without hand-derivation.

## Assembly: only the ESP header strips are populated parts

`J_PWR`, `J_SERVO`, `J_I2C_OLED`, `J_I2C_PCA`, and `J_I2S` are bare
through-holes for direct wire connections, not connector footprints to
populate — excluded from BOM/CPL at the footprint level (see above).

`J_ESP1`/`J_ESP2` are the one real part: **Kinghelm KH-2.54FH-1X9P-H3.5**
(LCSC/JLCPCB `C55778388`), a 2.54mm 1×9 THT female header. There's no 2×9 part
— the
ESP32-C3-Zero's socket needs **two** of these strips, one per row. The board
models this as two separate footprint objects, **`J_ESP1`** (the inner row,
nearer the wire end: 5V/GND/3V3/GPIO0-5) and **`J_ESP2`** (the outer row,
nearest the slot edge: GPIO21-GPIO6), each a real
9-pad object with its own designator — not one 2×9 footprint with a
quantity hint in prose. JLCPCB's assembly tooling (and most BOM tooling)
determines quantity by counting designators, not by parsing Comment text, so
a generated BOM lists both on one row as `"J_ESP1,J_ESP2"` (identical part,
JLC's own convention for grouping identical components) — that reads as qty
2 unambiguously.

A generated CPL has one row per designator, `J_ESP1` and `J_ESP2`, each at
its own row's real center — (13.00, 16.89) and (13.00, 1.65) in the board's
own coordinates — read directly by `kicad-cli pcb export pos` from each
footprint's own origin, no hand-derivation needed.

## Why this shape

Measured directly from an exported desk part (not estimated): the ESP mounting
slot is 25.0 × 18.5mm, and three of its four sides sit only 3.0–3.6mm from
full-height enclosure walls — too tight for any connector housing. Only the
front is open. That forced the layout:

- **26 × 44mm**, 2-layer.
- Back 18.5mm: 2×9 female socket for the ESP32-C3-Zero (2.54mm pitch,
  15.24mm row spacing — Waveshare's documented spec for the Zero board family,
  confirmed within 0.04mm of a direct caliper measurement).
- Front zone: `J_PWR` (now 4-pin — 5V/GND plus the external USB D+/D-, see
  below), `J_SERVO` (5V direct to PCA9685 V+, bypassing the ESP's own 3.3V
  regulator), `J_I2C_OLED`, `J_I2C_PCA` (separate connectors, bus shared via
  on-board copper — no external splitter cable), `J_I2S` (own on-board 5V
  feed for the amp).
- Everything routes fully on-board; nothing needs an off-board jumper.

## Pinout (rows stated in the frame that decides them)

Row placement is the part that is easy to get backwards, so name the rule:
**the pad map, seen from the face the module plugs into, has to be the
module's component-side view.** A pin-side view is the correct drawing only
for a socket on the *opposite* face — that inversion is exactly what went
wrong in the shipped batch (below).

Hold the C3-Zero component side up with its USB-C over this board's 5V-bus
edge (the long edge the 5V trace hugs). Then:

- **Outer row** — `J_ESP2`, nearest the slot edge (y=14.15):
  `GPIO21, GPIO20, GPIO19, GPIO18, GPIO10, GPIO9, GPIO8, GPIO7, GPIO6`.
  Mechanical/no-net support **except GP19 and GP18**, the native USB pair —
  see USB below.
- **Inner row** — `J_ESP1`, nearer the wire end (y=29.39):
  `5V, GND, 3V3, GPIO0(SDA), GPIO1(SCL), GPIO2(BCLK), GPIO3(LRCLK), GPIO4(DIN), GPIO5`

Pins 1 and 18 land at the 5V-bus edge in both rows, and that is what fixes
the module's USB-C to that edge. Traversing 1 to 18 reads counter-clockwise
from above, matching Waveshare's own pinout art (1-9 down the left column,
10-18 up the right, USB-C at the top).

## USB pass-through (external jack, not the C3-Zero's own USB-C)

Per `docs/hardware/interfaces.md`: the robot's single external USB-C (Adafruit
5993) carries both power and the ESP32's native USB D+/D- lines, so flashing
and serial CDC work through the panel-mount jack once the desk is sealed —
the C3-Zero's own onboard USB-C is left unused. No ESD or series-resistor
circuitry is specified for this link; it's a direct connection.

| `J_PWR` pin | Net | Goes to |
| --- | --- | --- |
| 1 | GND | common ground |
| 2 | D+ | ESP32 **GPIO19** (outer-row pad, native USB DP) |
| 3 | D− | ESP32 **GPIO18** (outer-row pad, native USB DM) |
| 4 | 5V | ESP32 5V rail, PCA9685 V+ (via `J_SERVO`), MAX98357A |

D+/D- run down the same 2.54mm grid columns as their own pads (x=20.42 and
22.96), which sits half a pitch off `J_I2C_OLED`/`J_I2C_PCA`'s grid, so they
never cross those connectors' pads on the way past. Since the row swap they
also pass the inner row, where the 3V3 and SDA holes occupy those two
columns, so each line takes one short lateral jog into the adjacent lane
(1.27mm off-axis, 0.42mm to the nearest pad edge) and returns — still F.Cu,
no vias. Each line measures 36.088mm and the two are exactly length-matched;
that is 16mm longer than before the swap, which is electrically unremarkable
at full-speed 12 Mbps.

## Mirrored socket map (boards in transit)

**The shipped boards (`carrier-fab-v3-replacement_Y5`) have the two socket
rows the wrong way round.** Their pad map is the C3-Zero seen from its *pin
side*, which is the correct drawing only for a socket on the opposite face;
as fabricated, a component-side-up module does not mate.

Caught by handedness, which no rotation can change: on the module
(component side, USB-C up) pins 1-9 run DOWN the left column and 10-18 UP
the right, so 1 to 18 is counter-clockwise; on those boards `J_ESP1` 1 to 9
runs left-to-right along the outer row and `J_ESP2` 10 to 18 right-to-left
along the inner row, i.e. clockwise.

**This revision fixes the source** — rows swapped in copper, nothing moved
mechanically. **For the boards in transit, fix it at assembly:** solder both
female strips to the **pour face** (B.Cu) and run that face up. From the
pour face you see the mirror of the F.Cu artwork, which is the
component-side map, so the module mates. What that build costs: the module's
own USB-C ends up over the long edge facing the opposite wall from this
revision's intent (unused either way — the Adafruit 5993 jack carries power
and CDC), the silkscreen ends up underneath so mark pin 1 before assembly,
and the wire-end connector positions mirror left-right, so the runs to the
PCA9685 / OLED / amp swap sides.

## Fab notes

- `kicad-cli pcb drc --severity-all` (KiCad 10.0.6, run *without*
  `--refill-zones` so it judges the on-disk fill) reports **0 violations and
  0 unconnected items** — and that statement now means something. The
  project's DRC floors used to be `min_clearance` 0.0, `min_silk_clearance`
  0.0, `min_text_height` 0.8 and `min_text_thickness` 0.08, so DRC could not
  have failed on clearance, silk overlap or undersized text however bad they
  got. They are now 0.2 / 0.15 / 1.0 / 0.15, matching JLCPCB's floors and
  its standard-font minimum. Schematic parity is not checked and cannot be —
  there is no `.kicad_sch` for this board, and `--schematic-parity` answers
  "Schematic parity tests require a fully annotated schematic".
- **Every pad on the board is named on silk.** The socket rows carry
  `GP21`-`GP6` (outer) and `5V, GND, 3V3, GP0`-`GP5` (inner) with a `USB`
  arrow pointing at the 5V-bus edge; each wire-end connector carries its own
  pin names (`3V3/SDA/SCL/GND` on both I2C headers, `5V/BCLK/LRC/DIN/GND` on
  `J_I2S`, `GND/D+/D-/5V` on `J_PWR`, `5V/GND` on `J_SERVO`). 48 silk items,
  all 1.0mm height / 0.15mm stroke. Placement is checked geometrically, not
  by DRC — 0 silk-to-silk overlaps, 0.421mm minimum silk-to-pad, 0.383mm
  minimum silk-to-edge. Before this the board carried nothing but seven
  reference designators, which is why a mirrored pad map was invisible both
  in the render and on the bare board.
- The seven reference designators were 0.8mm high with a 0.12mm stroke,
  under JLCPCB's standard-font minimum and passing DRC only because
  `min_text_thickness` was 0.08. All seven are now 1.0mm / 0.15mm.
  `J_I2C_PCA`, `J_PWR` and `J_SERVO` moved to clear the new pin-name bands,
  and every label is re-checked against the 0.30mm edge margin — three of
  them sit at exactly that margin, so the larger text boxes were nudged back
  inside rather than allowed to overhang.
- GND pour clearance raised 0.20 → 0.25mm — the zone's local clearance and
  the Default netclass together — and refilled. At 0.20 the fill sat at
  exactly JLCPCB's floor with nothing left for their etch tolerance; the
  nearest track-based constraint is 0.42mm, so the extra 0.05mm costs no
  geometry.
- 4 reference designators (`J_ESP1`, `J_ESP2`, `J_I2C_OLED`, `J_I2C_PCA`)
  were printing 0.2–0.6mm past the board's left edge — visually confirmed,
  not just a DRC technicality. Each footprint's own text bounding box (not
  an estimate) was used to shift the label right just enough to sit at a
  0.3mm margin from the edge; the render below reflects the fix.
- GND zone (B.Cu) outline is inset 0.5mm from the board edge, not 1mm as in
  earlier revisions — the 1mm inset put pads near the top edge (e.g. `J_ESP1`
  pin 2, GND) close enough to the zone's own boundary that a fresh zone
  refill could fail to route a thermal-relief connection to them, especially
  after the `J_ESP2` drill fix changed nearby pad geometry. Swept the inset
  from 1.0mm down to 0.3mm in 8 steps against the drill-fixed board, each
  with a fresh `kicad-cli pcb drc --refill-zones`: 1.0mm and 0.8mm both
  reproducibly fail with 1 unconnected pad; every value from 0.6mm down to
  0.3mm passes with 0. 0.5mm sits in the middle of that verified-safe range
  — well clear of the failure boundary and with real margin above JLCPCB's
  ~0.2–0.3mm copper-to-edge floor.
- Tightest feature: 0.15mm copper (GND pour minimum thickness). Comfortably
  inside JLCPCB's 0.127mm floor; sits exactly at PCBWave's 0.15mm floor (their
  recommended safe minimum is 0.20mm) — check their DFM report before ordering
  if using PCBWave.
- Connectors are plain 2.54mm through-hole pads (pin headers + jumpers), not
  JST — real JST-PH footprint dimensions weren't verified at design time.
- 5V trace sized per IPC-2221 (2A, 1oz copper, 10°C rise → ≈0.78mm minimum).
  The whole net is now 1.0mm over its 44.9mm length, with **no pinch points
  left**: the row swap moved the 5V pad off the outer row onto the inner one,
  15.24mm closer to its loads, which removed the squeeze past the mechanical
  pad row that previously forced two short 0.6mm sections.
  Any track change requires refilling the GND zone, and the refill must be
  done via KiCad itself (GUI Fill All Zones + save, or the
  `pcbnew.ZONE_FILLER` Python API) and re-verified with `kicad-cli pcb drc`
  run *without* `--refill-zones` — that flag only recomputes the fill
  in-memory for the check, it does not persist to the file, so a stale
  on-disk fill can pass DRC while still being wrong in the Gerbers. This bit
  us once already in this revision's history.

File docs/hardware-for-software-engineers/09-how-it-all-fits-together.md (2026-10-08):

# How it all fits together

You've read the pieces. This chapter closes the loop on the guide's goal — **from software-only to hardware-capable** — then hands you to the build checklist. Tiny Engineer is the capstone: one system where electricity, firmware, buses, print, and motion connect. The vocabulary you picked up travels with you to the next board.

**Expect medium difficulty overall** — not an entry-level blinky kit, but a fair first hardware build for a software engineer who read the guide and validates electronics on the desk (connect + flash) before closing the chest. The default build is the main control board. Harness examples in this guide are the advanced path — [wiring.md](../hardware/wiring.md). Hardest areas for most SWEs: wiring density on that advanced path, servo mechanics, power under load. Easiest: REST and Wi-Fi once that smoke check is solid.

---

## Three phases

```mermaid
flowchart TB
  subgraph learn [Learn phase]
    A[Electricity basics]
    B[MCU + buses]
    C[Print + mechanics]
  end

  subgraph build [Build phase]
    D[Print parts]
    E[Wire_flash_desk_smoke]
    F[Assemble]
  end

  subgraph run [Run phase]
    H[Wi-Fi + web UI]
    I[REST API + agent hooks]
  end

  learn --> build --> run
  D --> E --> F
```

**Learn** — this guide. Enough to not fry boards.

**Build** — [getting-started.md](../getting-started.md). Checklist: shop, print, connect, flash, assemble, wizard, prove.

**Run** — Wi-Fi, `/anim`, Cursor hooks or your own integration.

You can overlap phases (print while reading). Don't skip **desk smoke** (serial, PCA9685, one servo) before seating the board in the chest.

---

## The whole robot — one diagram

```mermaid
flowchart TB
  Agent["AI agent / curl / web UI"]
  Agent -->|HTTP Wi-Fi 2.4GHz| ESP["ESP32-C3-Zero"]

  subgraph power [Power from board USB-C]
    V5[5V rail]
    V33[3.3V logic via LDO]
  end

  ESP --> V5
  V5 --> V33

  ESP -->|I2C GP0/1| PCA["PCA9685 0x40"]
  ESP -->|I2C GP0/1| OLED["OLED 0x3C"]
  ESP -->|I2S GP2-4| AMP["MAX98357A"]
  AMP --> SPK[Speaker]

  V33 --> PCA
  V33 --> OLED
  V5 --> AMP
  PCA -->|V+ 5V PWM| SRV["5 analog micro servos"]

  PCA --> SRV

  subgraph mech [Printed mechanics Fusion to 3mf]
    BODY[Head Neck Hands Body]
  end

  SRV --> BODY
  ESP -.->|antenna keep-out| BODY
```

**Control plane:** Wi-Fi HTTP from your LAN.

**Data paths:** I2C for servos (via PCA9685) and display; I2S for audio.

**Power plane:** One 5 V in; 3.3 V logic derived; servos on 5 V motor rail.

**Mechanical plane:** Fusion CAD → printed parts → servos → pose.

---

## Subsystem → chapter map

| Subsystem | Learn in | Operate with |
| --- | --- | --- |
| Volts, amps, GND, two domains | Ch. 01, 07 | [power.md](../hardware/power.md) |
| ESP32-C3, GPIO, USB, antenna | Ch. 02 | [pinout.md](../hardware/pinout.md) |
| Wires, schematic reading | Ch. 03 | [main-control-board.md](../hardware/main-control-board.md). Advanced: [wiring.md](../hardware/wiring.md), [diagram](../wiring/Tiny%20Engineer.drawio.png) |
| I2C, I2S, PWM | Ch. 04 | [interfaces.md](../hardware/interfaces.md) |
| Servos, horns, joints | Ch. 05 | [robot-movement.md](../robot-movement.md), [servos.md](../hardware/servos.md) |
| Print, PLA/PETG, Fusion | Ch. 06 | [3d_models/README.md](../../3d_models/README.md) |
| Supply sizing, brownout | Ch. 07 | [power.md](../hardware/power.md) |
| pio, serial, bisect debug | Ch. 08 | [testing.md](../hardware/testing.md) |
| HTTP API, agents | — (after hardware) | [integration.md](../integration.md) (`tiny-engineer` CLI), [api.md](../api.md), Cursor detail: [hooks.md](../hooks.md) |

---

## Recommended build strategy (software brain edition)

Follow the checklist in [getting-started.md](../getting-started.md). Summary:

1. **Shop** → [shopping.md](../shopping.md) (main control board)
2. **Print or order** (can overlap with learning) → [3d_models](../../3d_models/README.md)
3. **Connect** + **flash** on the desk → [main-control-board.md](../hardware/main-control-board.md), then [flash.md](../flash.md). Extra modules: [wiring.md](../hardware/wiring.md)
4. **Assemble** (one run: Head/Hat, centering, joins) → [assembly.md](../3d/assembly.md) §§1–19
5. **Setup wizard** → assembly §20
6. **Prove** (`/health`, `ring`) → [getting-started §7](../getting-started.md#7-prove-it)
7. **Agent hooks** → [integration.md](../integration.md) (`tiny-engineer setup`); Cursor detail: [hooks.md](../hooks.md)

**Desk smoke is first:** with boards still on the desk, confirm serial boot, PCA9685 OK, and one servo via `/test/servo` or setup AP **Move all to 90°**. Then one mechanical run. Do not finish the wizard until §20.

**Temptation to avoid:** printing everything beautifully before verifying electronics. Pretty plastic won't fix a swapped SDA/SCL.

---

## Confidence milestones

Check these off — order matches the checklist:

| # | Milestone | When | How you know |
| --- | --- | --- | --- |
| 1 | **Continuity sanity** | connect | No short 5V–GND; GND common (meter, power off) |
| 2 | **Serial boot** | flash | `pio device monitor` shows boot log, dim green LED |
| 3 | **PCA9685 detected** | flash | Serial OK; missing = 1 red blink, hang ([blink codes](../hardware/testing.md#boot-failure-blink-codes)) |
| 4 | **One servo / 90°** | flash | Setup AP **Move all to 90°** or `/test/servo` moves a channel |
| 5 | **Joints in safe range** | assembly §§1–19 | Each joint centered and joined; no stall buzz |
| 6 | **Board seated** | late assembly | Same electronics checks still pass after mounting in the chest |
| 7 | **Wi-Fi stable** | after §20 wizard | `/health` over `tiny-engineer.local` or OLED IP |
| 8 | **Audio + full anim** | prove it | e.g. `ring` — motion + sound (if silent → `uploadfs`) |
| 9 | **Agent** | optional | Cursor hook or script triggers `/anim` |

Stuck on a milestone? Back one step, read [Ch. 08](08-tools-debugging-and-embedded-workflow.md) and [testing.md](../hardware/testing.md).

---

## What I'd tell any software engineer starting hardware

Not specific to day one on Tiny Engineer — things that stayed true across projects:

1. **Two voltages, one GND** — not optional mental model
2. **PCA9685 isn't optional** — plan I2C before servos
3. **Power is a feature** — 2 A supply saves hours of "random reboot" debugging
4. **Horns are calibration** — software clamps can't fix physical collision
5. **Wire + flash on the desk first, then one mechanical run** — smoke before closing the chest
6. **The docs split on purpose** — this guide for *why*, getting-started for *do*, hardware/ for *lookup*

The meta-lesson: hardware rewards the same curiosity that got you into software, but feedback is louder — smoke, buzz, heat. That's part of the fun.

---

## Handoff — go build

You're done with concepts when the milestones make sense and you know which doc to open for pin numbers.

**Operational checklist:** [getting-started.md](../getting-started.md)

**Shop → print → wire → flash → assemble → wizard → prove → hooks.**

If you're mostly a software person: good. The bar isn't an EE degree — it's curiosity and willingness to probe a wire. In a world where AI spits out code in seconds, there's a particular joy in something on your desk that moves because *you* closed the loop from schematic to screw. Tiny Engineer is a fun capstone — but the bridge you built here works for the next project too.

---

**Next:** none — start building, or re-read any chapter from the [README](README.md).

**Reference:** [getting-started.md](../getting-started.md) · [hardware/README.md](../hardware/README.md) · [README.md](README.md)

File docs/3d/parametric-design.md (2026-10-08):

# Parametric design (different servo sizes)

[`3d_models/cad/TinyEngineer.f3d`](../../3d_models/cad/TinyEngineer.f3d) is the parametric Fusion source for the robot. Printed pockets, mounting tabs, shaft clearance, and M2 screw pilots are driven by Fusion **user parameters**. Change those values and the assembly rebuilds for a different micro servo or a tighter/looser screw fit.

Presets live in [`servos.json`](../../3d_models/fusion/TinyEngineerTools/servos.json). **TinyEngineer Tools** writes them into the `.f3d`, then exports print meshes under `parts/{servo_id}/3mf/` (and matching `stl/`) plus STEP CAD under `parts/{servo_id}/step/`.

```mermaid
flowchart LR
  json["servos.json presets"]
  cfg["Servo Configurator"]
  f3d["TinyEngineer.f3d user params"]
  parts["parts/servo_id meshes"]
  json --> cfg --> f3d --> parts
```

## Which servo

Servo size sets the size of the **whole robot**. Desk, chair, body, and pockets all scale with the preset. Pick the servo first, then print the matching `parts/{servo_id}/3mf/` folder.

Built-in presets in [`servos.json`](../../3d_models/fusion/TinyEngineerTools/servos.json):

| Model | `servo_id` | When to use |
| --- | --- | --- |
| **Tower Pro SG90** (recommended) | `sg90` | Easiest to buy. Bigger desk — electronics are easier to fit and assemble. |
| **Feetech FS0307** | `fs0307` | More compact. Looks better if you want a smaller robot. |
| **EMAX ES9051** | `es9051` | Compact — similar footprint to FS0307, slightly taller body. |
| **PowerHD HD-1370A** | `hd1370a` | Still supported for backward compatibility. Not the pick for a new build. |

A non-standard servo is fine: measure it, add a preset, run the configurator ([Add a new servo](#add-a-new-servo)). Print parts that match that `servo_id`.

Print matching `parts/{servo_id}/3mf/`: [`sg90`](../../3d_models/parts/sg90/3mf/), [`fs0307`](../../3d_models/parts/fs0307/3mf/), [`es9051`](../../3d_models/parts/es9051/3mf/), [`hd1370a`](../../3d_models/parts/hd1370a/3mf/).

## Servo parameters

Each preset in `servos.json` is a map of Fusion user-parameter names to expressions such as `"20 mm"`. The configurator ([`servo.py`](../../3d_models/fusion/TinyEngineerTools/servo.py)) writes those into the open design. It refuses names that are not already user parameters in the `.f3d` — do not invent keys.

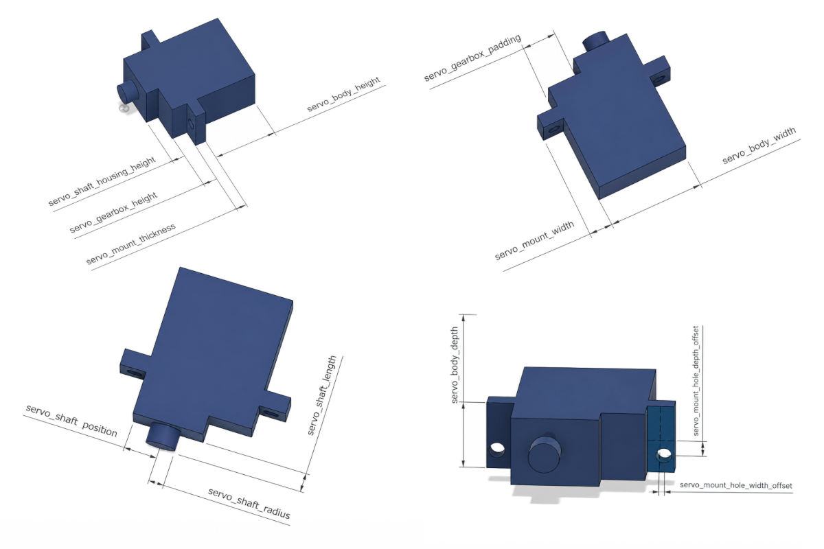
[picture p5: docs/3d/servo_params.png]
Servo body dimensions used as Fusion user parameters


### Body and tabs

| Parameter | Meaning |
| --- | --- |
| `servo_body_width` | Body length between the two mounting tabs (tabs not included). |
| `servo_body_height` | Body height, from the mounting-tab plane to the opposite face. |
| `servo_body_depth` | Body thickness (front to back). |
| `servo_mount_width` | How far each mounting tab sticks out from the body. |
| `servo_mount_thickness` | Tab thickness. |

### Gearbox and shaft stack

| Parameter | Meaning |
| --- | --- |
| `servo_gearbox_height` | Gearbox step sitting on the body. |
| `servo_shaft_housing_height` | Boss around the output shaft, above the gearbox. |
| `servo_gearbox_padding` | How far the gearbox / shaft stack is inset from the body edge (the asymmetric “fat” side of typical micro servos). |

### Shaft

| Parameter | Meaning |
| --- | --- |
| `servo_shaft_position` | Distance from the body end to the shaft axis. |
| `servo_shaft_length` | How far the spline shaft sticks out. |
| `servo_shaft_radius` | Shaft radius (not diameter). |

### Mount holes

`servo_mount_hole_radius` is in `servos.json` but not drawn on the diagram.

| Parameter | Meaning |
| --- | --- |
| `servo_mount_hole_depth_offset` | Hole shift along body depth from the tab centerline. |
| `servo_mount_hole_width_offset` | Hole shift along the tab (toward or away from the body). |
| `servo_mount_hole_radius` | Screw-hole radius in the tabs. |

### Not a dimension

| Parameter | Meaning |
| --- | --- |
| `servo_id` | Short lowercase folder id (`hd1370a`, `fs0307`, `sg90`, `es9051`). The configurator writes it; the exporter uses it. |

## M2 screw holes

Assembly uses **M2 screws** that thread directly into the printed PLA/PETG (no heat-set inserts). Pilot-hole size is a Fusion **user parameter**, not a servo preset:

| Parameter | Meaning |
| --- | --- |
| `screw_thread_diameter` | Modeled diameter of M2 self-tapping pilot holes in the printed parts. |

Related (usually leave alone): `screw_head_diameter`, `screw_head_height` — countersink / head clearance for the same fasteners.

`screw_thread_diameter` is **not** in [`servos.json`](../../3d_models/fusion/TinyEngineerTools/servos.json). Change it in Fusion (**Modify → Change Parameters**), then run **Tiny Engineer Parts Exporter** again.

### Why dial it in

Print tolerances vary by printer, material, and slicer. FDM holes often print smaller than modeled, so the CAD default is slightly oversized relative to an M2 major diameter (~2.0 mm). On some printers the hole still comes out large enough that the screw **slides through** instead of cutting a thread — mounting gets loose.

### Use `ScrewSizingTest` first

1. Print [`ScrewSizingTest.3mf`](../../3d_models/README.md#print-first) from your `parts/{servo_id}/3mf/` folder (quick, small).
2. Each hole is labeled with its diameter (about **2.00–2.40 mm** in **0.05 mm** steps).
3. Drive an M2 screw into each hole. Prefer the **tightest** hole that still lets the screw cut a clean thread (firm bite, not free-spinning, not so tight you strip the plastic).
4. Set `screw_thread_diameter` to that labeled value and re-export before printing the full set.

Print [`ServoSizingTester`](../../3d_models/README.md#print-first) in the same “print first” pass for servo pocket fit.

### Recommended / tested values

| Value | When |
| --- | --- |
| **2.1 mm** | CAD default and shipped `parts/*/3mf/` exports. Tested path on a **Creality Ender 3 V3 SE**, PLA, ~0.16 mm layer height ([printing notes](../hardware-for-software-engineers/06-3d-printing-and-mechanical-build.md)). |
| Smaller (e.g. 2.05–2.15 mm) | Pilot too tight to start a thread without cracking — pick from `ScrewSizingTest`. |
| Larger (e.g. 2.25–2.35 mm) | Screws feel loose / slide through on your printer — pick from `ScrewSizingTest`. |

Always trust **your** `ScrewSizingTest` result over the table if they disagree.

## TinyEngineer Tools add-in

**TinyEngineer Tools** is a Fusion add-in for [`cad/TinyEngineer.f3d`](../../3d_models/cad/TinyEngineer.f3d). It writes servo dimensions from [`TinyEngineerTools/servos.json`](../../3d_models/fusion/TinyEngineerTools/servos.json) into Fusion user parameters, and exports selected `PRINT_LAYOUT` children as `.3mf` / binary `.stl` / `.step` (PRINT_LAYOUT with one child visible, so captured print pose stays). STL/3MF use Save as Mesh; STEP uses File → Export.

Fusion must know about the add-in folder. Folder name, `TinyEngineerTools.py`, and `TinyEngineerTools.manifest` must stay the same.

Official Autodesk steps: [How to install an add-in or script](https://www.autodesk.com/support/technical/article/caas/sfdcarticles/sfdcarticles/How-to-install-an-ADD-IN-and-Script-in-Fusion-360.html).

### Point Fusion at this repo

Fusion remembers the path. Code stays in git. Reload after edits (see below).

1. Open Fusion.
2. Open **Utilities → Add-Ins → Scripts and Add-Ins**. Shortcut: **Shift+S**.
3. Open the **Add-Ins** tab.
4. Click the green **+** next to **Script of add-in from device**.
5. Browse to `3d_models/fusion/TinyEngineerTools/` in this repo and select the folder.
6. Select **TinyEngineerTools** in the list and click **Run**.
7. Optional: enable **Run on Startup** so Fusion starts it every launch.

### Use the commands

Open [`cad/TinyEngineer.f3d`](../../3d_models/cad/TinyEngineer.f3d) and stay in the **Design** workspace. Both commands live under **Utilities → Add-ins**.

#### TinyEngineer Servo Configurator

Select a servo model and apply dimensions, including `servo_id` (short lowercase id such as `sg90`).

The command reads [`servos.json`](../../3d_models/fusion/TinyEngineerTools/servos.json), previews the values, and writes them into the design’s user parameters. Use this to preview a preset in the open design; Parts Exporter can also apply selected servos during export.

#### Tiny Engineer Parts Exporter

A command dialog asks what to export (all checkboxes **on** by default):

* **Servos** — each preset in [`servos.json`](../../3d_models/fusion/TinyEngineerTools/servos.json)
* **Parts** — each direct `PRINT_LAYOUT` child in a scrollable table, with **Select all** / **Deselect all**
* **Formats** — `3MF`, `STL`, `STEP`

Then choose an export folder.

For each selected servo the add-in applies that preset’s parameters, then exports each selected part separately. For each part it temporarily hides the others, keeps that child visible in its saved print orientation, and writes the checked formats under that servo’s folder:

* `{servo_id}/3mf/{name}.3mf` (if 3MF selected)
* `{servo_id}/stl/{name}.stl` binary STL (if STL selected)
* `{servo_id}/step/{name}.step` STEP CAD via File → Export (if STEP selected)
* `{servo_id}/README.md` with that servo’s parameters from `servos.json`

After the run, visibility and the design’s previous servo parameters are restored. A progress dialog stays up so Fusion can paint; Cancel stops after the current part.

## Add a new servo

1. Measure a real unit (prefer calipers over datasheet marketing sizes).
2. Copy an existing object in [`servos.json`](../../3d_models/fusion/TinyEngineerTools/servos.json); keep the same keys; set a unique `servo_id`.
3. Reload the add-in, run Servo Configurator, confirm Fusion parameters update.
4. Print [`ServoSizingTester`](../../3d_models/README.md#print-first) and [`ScrewSizingTest`](../../3d_models/README.md#print-first) first (servo pocket + M2 pilot), then export.

The configurator refuses unknown Fusion parameter names. Do not invent keys that are not already user parameters in the `.f3d`.

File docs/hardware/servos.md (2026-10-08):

# Servos

## Hardware

| Item | Value |
| --- | --- |
| Model | Analog micro servo — **Tower Pro SG90 recommended** ([presets](../3d/parametric-design.md)) |
| Count | 5 |
| Driver | Adafruit PCA9685, I2C `0x40` |
| Servo supply | PCA9685 **V+** ← drawing: USB **5V** → PCA9685 **5V** (same servo rail as **V+**; not **VCC**) |
| PWM frequency | **50 Hz** (`pwm.setPWMFreq(50)`) |
| Channels | 0, 1, 2, 3, 4 (`SERVO_HEAD`…`SERVO_BODY` in `SERVO_SPECS`) |

> [!WARNING]
> Never power the servos from the ESP32 3.3 V regulator.

## Electrical PWM range

Manufacturer pulse window used in firmware:

| Constant | Value |
| --- | --- |
| `SERVO_MIN_US` | **800** µs |
| `SERVO_MAX_US` | **2200** µs |
| Neutral (typical) | ~1500 µs (90° in the firmware 0–180 map) |

`angleToPulse()` in [`src/hardware/servo_wrapper.cpp`](../../src/hardware/servo_wrapper.cpp) maps firmware angle **0–180°** linearly onto 800–2200 µs, then onto PCA9685 12-bit counts assuming a **20 000 µs** period (rounded to nearest count):

`counts = round(pulse_us * 4096 / 20000)`

Effective angular spacing is **~0.63° per count** (~288 distinct positions over 180°). `writeAngle()` skips redundant I2C writes when the rounded count is unchanged. The PCA9685 keeps emitting that last pulse until a later write — skipping I2C does **not** turn the servo off.

Datasheet travel over 800–2200 µs is **approximately 130°**, while many sellers list 0–180°. Firmware still uses a 0–180 mathematical scale. That scale is **not** a promise of mechanical 180° in the robot.

## Current firmware test limits

Verified in [`include/pins.h`](../../include/pins.h) and [`include/servos.h`](../../include/servos.h):

| Constant | Value | Role |
| --- | --- | --- |
| `SERVO_STEP_MS` | 10 | Live update / interpolation step (ms) |
| `SERVO_ANGLE_DEADBAND_DEG` | **0.32** | Stop threshold (~half PWM count) |
| `SERVO_PWM_RELEASE_DELAY_MS` | **2000** | After idle/sleep park, hold PWM this long then full-off |
| `SERVO_MAX_SPEED_DEG_S` | **140.0** | Smooth rate for `POST /test/servo` |
| `SERVO_BOOT_SPEED_DEG_S` | **35.0** | Boot centering and sleep-pose moves |

## Boot safety

On every boot (and after each flash reset):

1. **OE** — GP5 drives PCA9685 **OE** (active LOW). Firmware holds OE **HIGH** (outputs off) from early `setup`, then **LOW** after neutral PWM is written (`PCA9685_OE_WIRED = true` in [`include/pins.h`](../../include/pins.h)).
2. **Early init** — PCA9685 is probed and configured immediately after `Wire.begin`, before OLED, settings, or Wi-Fi.
3. **Neutral park** — all channels receive mid-pulse PWM while OE is still HIGH; then OE goes LOW.
4. **Smooth boot moves** — `centerAllServos()` and sleep-inertia pose use `servoMoveAllSmoothTo()` at `SERVO_BOOT_SPEED_DEG_S` (35°/s), not instant snaps.

## Idle and sleep PWM release

Analog servos hunt while a 50 Hz pulse is present. Firmware does **not** use OE for this: after animation `none` parks (awake rest or device-sleep chin-down) and every joint is still for `SERVO_PWM_RELEASE_DELAY_MS` (**2000** ms), it writes PCA9685 full-off (`setPWM(channel, 0, 4096)`) on channels 0–4. SIG stays low; the servo goes **limp** (no holding torque). Head pitch can droop; hands-down usually rests on the desk.

The next animation, `/test/servo`, or `/setup/servo` rewrite the last commanded pulse before moving. Leaving `none` restores all five channels at their last angles first.

**Setup AP** (`wifiProvisioningMode`) never releases PWM, so “Move all to 90°” / horn install still holds.

## Motion modes

Firmware uses two complementary control paths:

| Mode | API | Use |
| --- | --- | --- |
| **Choreographed** | `setNormPosition()` + time easing (`anim::easedLerp`, `anim::EasedMove`) | Welcome raise/wiggle, thinking head/neck — pose in −1..1, mapped to saved min/max each frame |
| **Discrete** | `setNormTarget()` + `update()` slew | Typing, reading, ring, transitions — rate-limited chase to a mapped pose |

Helpers live in [`src/animation/util.cpp`](../../src/animation/util.cpp). Blocking test moves (`moveTo`) also use cubic easing.

`SERVO_MAX_SPEED_DEG_S` (140°/s) is ~28% of PowerHD HD-1370A unloaded max (~500°/s @ 4.8 V) — smoother under load while staying responsive for hand taps. Other presets (SG90, FS0307, ES9051) still use this firmware cap.

Bring-up motion (`runServoTest`): each joint uses its **saved** min/max (`n` in −1..1):

1. All channels → mid (`n = 0`)
2. Smooth mid → +0.5 (75% of span)
3. Smooth +0.5 → −0.5 (25% of span)
4. Smooth −0.5 → mid

This is a wiring/power test, not a pose library.

## Three ranges (do not collapse them)

| # | Range | Meaning | Current status |
| --- | --- | --- | --- |
| 1 | Electrical PWM | Pulse widths the servo electronics accept (~800–2200 µs @ 50 Hz) | In firmware |
| 2 | Nominal manufacturer angle | Marketing / datasheet travel (0–180° **or** ~130° over full pulse — sources disagree) | Do not trust for installed mechanics |
| 3 | Mechanical safe range | Per-joint min/max after horns and linkages | Stock defaults in `SERVO_SPECS` ([`include/servos.h`](../../include/servos.h)); saved to NVS in the setup AP wizard. See [robot-movement.md](../robot-movement.md) |

Animations author poses in **−1..1** (min / mid / max of range 3) and map through `servoNormToDeg`. `POST /test/servo` still takes electrical degrees and clamps to range 3. Setup AP `POST /setup/servo` uses range 1 (0–180°) to find limits.

Blind 0–180° on the assembled robot can stall gears, tear horns, or brown out the 5 V rail. Stay inside the saved min/max (stock `SERVO_SPECS` until you calibrate in setup AP).

## Channel-to-mechanism mapping

See [robot-movement.md](../robot-movement.md) for layout, axis directions, and per-servo safe angles (`include/servos.h`).

Related: [main-control-board.md](main-control-board.md), [power.md](power.md), [testing.md](testing.md). Advanced harness: [wiring.md](wiring.md).

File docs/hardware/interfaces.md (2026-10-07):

# Interfaces

Pin numbers match [`include/pins.h`](../../include/pins.h) and [pinout.md](pinout.md).

## I2C

Shared bus.

| Signal | ESP32 GPIO | Diagram pad |
| --- | --- | --- |
| SDA | GPIO0 | GP0 → PCA9685 SDA, OLED SDA |
| SCL | GPIO1 | GP1 → PCA9685 SCL, Waveshare OLED **SCL** |

| Device | Address | Firmware behaviour if missing |
| --- | --- | --- |
| PCA9685 | **`0x40`** | Hard fail: hang, 1 red blink (see [blink codes](testing.md#boot-failure-blink-codes)) |
| SSD1306 OLED | **`0x3C`** | Soft fail: tests continue without display |

Bus start: `Wire.begin(I2C_SDA, I2C_SCL)` with no explicit frequency → Arduino-ESP32 default (typically **100 kHz**). Not set in this repo.

PCA9685 **VCC** = **3V3**. OLED **VCC** = **3V3**. Pull-ups are on the main control board and on a typical OLED; the Adafruit PCA9685 breakout has its own. No extra pull-ups.

## I2S

Device: **MAX98357A** (mono class-D). No MCLK wire.

| Signal | ESP32 GPIO | Amp pin (as drawn) |
| --- | --- | --- |
| BCLK | GPIO2 / GP2 | BCLK |
| WS / LRC | GPIO3 / GP3 | LRC |
| DATA | GPIO4 / GP4 | DIN |

Bring-up configuration in [`src/main.cpp`](../../src/main.cpp):

| Parameter | Value |
| --- | --- |
| Mode | `I2S_MODE_STD` |
| Sample rate | **22050** (`SAMPLE_RATE`) |
| Width | `I2S_DATA_BIT_WIDTH_16BIT` |
| Slots | `I2S_SLOT_MODE_STEREO` |

Firmware writes identical samples to both stereo slots. MAX98357A is mono. On the main control board, gain is the solder jumper next to the amplifier ([board README](../../hardware/boards/main-control-board/README.md)). On the advanced breakout, **GAIN** and **SD** stay unwired (GAIN floating ≈ 9 dB, SD pulled up ≈ left channel) — [wiring.md](wiring.md).

On the main control board, amp **Vin** is **AUDIO_5V** (net-tied from **SERVO_5V** after the eFuse), not raw USB **+5V** — [power.md](power.md). On the advanced breakout, amp **Vin** is the shared USB **5V** rail — [wiring.md](wiring.md). I2S wires are 3.3 V logic. Speaker connects to **SPK+** / **SPK−** — [main-control-board.md](main-control-board.md).

> [!WARNING]
> MAX98357A SPK- is not ground.

## Servo PWM

Generated by **PCA9685**, not by ESP32 LEDC/MCPWM.

- I2C command from ESP32
- 12-bit PWM, **50 Hz**
- Channels 0–4
- Pulse mapping: [servos.md](servos.md)

ESP32 GPIO is not wired to servo SIG lines.

### PCA9685 output enable

| Signal | ESP32 GPIO | Notes |
| --- | --- | --- |
| OE | GPIO5 / GP5 | **Active LOW** — outputs enabled. Firmware drives **HIGH** during PCA9685 init, then **LOW** after neutral PWM is written |

Default on (`PCA9685_OE_WIRED = true` in [`include/pins.h`](../../include/pins.h)). Blocks invalid PWM during boot and flash resets. Set `PCA9685_OE_WIRED` to `false` only if OE is hard-tied off-chip (e.g. permanently to GND) so firmware must not drive GP5.

## USB

Single USB-C on the robot: the **main control board**.

| Net | Board USB-C | ESP32 / loads |
| --- | --- | --- |
| VBUS | through fuse → **+5V** | ESP32 **5V** pad; eFuse input → **SERVO_5V** (servos + amp) |
| GND | common GND | **GND** |
| D− | data | **GPIO18** |
| D+ | data | **GPIO19** |

One cable for robot power, flash, and serial CDC (`ARDUINO_USB_MODE=1`, `ARDUINO_USB_CDC_ON_BOOT=1`, monitor 115200). Leave the C3-Zero onboard USB-C unused when the board USB-C supplies power and data — [power.md](power.md).

The advanced path wires the same nets from an Adafruit 5993 — [wiring.md](wiring.md#usb-connector-5993).

C3-Zero has **no** USB–UART bridge. If CDC does not enumerate, hold **BOOT (GPIO9)** then attach USB (Waveshare flashing note).

## Not used

| Interface | Pads | Notes |
| --- | --- | --- |
| UART0 | GPIO21 TX / GPIO20 RX | Silkscreen; console is USB CDC |
| BLE | antenna | Hardware may be present; **out of scope** — product uses Wi-Fi only |
| ESP32 onboard USB-C | — | Unused when the board USB-C supplies power + data |

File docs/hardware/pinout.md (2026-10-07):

# Pinout

Source of truth: [`include/pins.h`](../../include/pins.h). This file must match that header.

## Assigned ESP32-C3-Zero GPIO

| Function | ESP32-C3-Zero GPIO | Constant | Goes to |
| --- | --- | --- | --- |
| I2C SDA | **GPIO0** (diagram **GP0**) | `I2C_SDA` | PCA9685 SDA, OLED SDA |
| I2C SCL | **GPIO1** (diagram **GP1**) | `I2C_SCL` | PCA9685 SCL, Waveshare OLED **SCL** |
| I2S BCLK | **GPIO2** (diagram **GP2**) | `I2S_BCLK` | MAX98357A BCLK |
| I2S LRCLK / WS | **GPIO3** (diagram **GP3**) | `I2S_LRC` | MAX98357A **LRC** |
| I2S DATA OUT | **GPIO4** (diagram **GP4**) | `I2S_DIN` | MAX98357A DIN |
| PCA9685 OE | **GPIO5** (diagram **GP5**) | `PCA9685_OE_PIN` | PCA9685 **OE** (active LOW; `PCA9685_OE_WIRED`) |
| Built-in WS2812 RGB | **GPIO10** | `RGB_LED_PIN` | onboard LED only |

Logic level: **3.3 V**.

## Reserved / unavailable

| GPIO | Status | Reason |
| --- | --- | --- |
| GPIO9 | **Reserved** | BOOT / strapping. On the main control board it is also on **J4** (extension only) — do not pull low at reset (download mode). Do not pick casually for peripherals |
| GPIO10 | **Occupied** | Onboard WS2812 |
| GPIO12–GPIO17 | **Unavailable** | Stacked flash, not brought out |
| GPIO18 | **Reserved** | Native USB D− (main control board USB-C; advanced path: [5993](wiring.md#usb-connector-5993)) |
| GPIO19 | **Reserved** | Native USB D+ (main control board USB-C; advanced path: [5993](wiring.md#usb-connector-5993)) |

## Free / default-function pads

| GPIO | Status | Notes |
| --- | --- | --- |
| GPIO6 | Free | Brought out on **J4** (main control board) |
| GPIO7 | Free | Brought out on **J4** |
| GPIO8 | Free | Brought out on **J4**; strapping — do not pull low at reset |
| GPIO20 | Default UART0 RX | Silkscreen RX; also on **J4**. Free for other use only if USB CDC remains the console (`ARDUINO_USB_CDC_ON_BOOT=1`) |
| GPIO21 | Default UART0 TX | Silkscreen TX; also on **J4**. Same caveat as GPIO20 |

Power pads (not GPIO): **5V**, **GND**, **3V3**.

## Main control board headers

Pin order matches the KiCad board and [`expected-nets.yml`](../../hardware/boards/main-control-board/expected-nets.yml). Board overview: [board README](../../hardware/boards/main-control-board/README.md).

### J2 — OLED (`Conn_OLED`)

| Pin | Net |
| --- | --- |
| 1 | **+3.3V** |
| 2 | **GND** |
| 3 | **I2C SDA** |
| 4 | **I2C SCL** |

### J3 — I2C extension (`Conn_extension`, JST)

Same bus as J2 / PCA9685. **Pin order is not the same as J2** (GND and 3.3 V are swapped).

| Pin | Net |
| --- | --- |
| 1 | **GND** |
| 2 | **+3.3V** |
| 3 | **I2C SDA** |
| 4 | **I2C SCL** |

### J4 — 12-pin extension (`Conn_02x06_Odd_Even`)

| Pin | Net |
| --- | --- |
| 1 | **SERVO_5V** |
| 2 | **GP21** (default UART0 TX) |
| 3 | **GND** |
| 4 | **GP20** (default UART0 RX) |
| 5 | **GND** |
| 6 | **GP9** (strapping / BOOT — do not pull low at reset) |
| 7 | **+3.3V** |
| 8 | **GP8** (strapping — do not pull low at reset) |
| 9 | **I2S BCLK** |
| 10 | **GP7** |
| 11 | **I2S LRC** |
| 12 | **GP6** |

I2S **DIN** is not on J4 (ESP32 → amp only). **SERVO_5V** is the eFuse-protected rail — [power.md](power.md).

## PCA9685 channels (not ESP32 GPIO)

| PCA9685 channel | Firmware | Mechanism |
| --- | --- | --- |
| 0 | `SERVO_HEAD` | Head pitch — [robot-movement.md](../robot-movement.md) |
| 1 | `SERVO_NECK` | Neck yaw |
| 2 | `SERVO_HAND_LEFT` | Left hand |
| 3 | `SERVO_HAND_RIGHT` | Right hand |
| 4 | `SERVO_BODY` | Body / torso |
| 5–15 | unused | available |

## Other constants in `pins.h` (not pins)

| Constant | Value | Meaning |
| --- | --- | --- |
| `SAMPLE_RATE` | 22050 | I2S sample rate |
| `PCA9685_ADDRESS` | `0x40` | I2C |
| `OLED_ADDRESS` | `0x3C` | I2C |
| `OLED_WIDTH` / `OLED_HEIGHT` | 128 / 32 | Display |
| `SERVO_MIN_US` / `SERVO_MAX_US` | 800 / 2200 | Electrical PWM span |
| `SERVO_BOOT_SPEED_DEG_S` | 35 | Boot centering / sleep-pose rate (deg/s) |
| `PCA9685_OE_WIRED` | `true` | GP5 drives PCA9685 OE (active LOW). Set `false` only if OE is hard-tied off-chip |

## Pin allocation rules

New hardware **must not** pick pins ad-hoc.

1. Choose a pad from the **Free** table above, or a documented unused PCA9685 channel.
2. Do not use **Reserved** or **Unavailable** pins.
3. Update **both**:
   - [`include/pins.h`](../../include/pins.h)
   - this `pinout.md`
4. Update [interfaces.md](interfaces.md) and, when the harness or the board plugs change, [main-control-board.md](main-control-board.md) and [wiring.md](wiring.md) in the same change.
5. Stay in the **3.3 V** GPIO domain. Level-shift if a new device is 5 V-only.
6. I2C devices need a unique address on the shared GPIO0/GPIO1 bus.
7. After the edit, grep the repo for old GPIO numbers so comments and tests stay consistent.

Related: [main-control-board.md](main-control-board.md), [interfaces.md](interfaces.md). Advanced harness: [wiring.md](wiring.md).

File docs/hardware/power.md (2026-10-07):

# Power

## Architecture

USB-C brings in a **nominal 5 V**. On the [main control board](../../hardware/boards/main-control-board/README.md) that splits into a logic/host rail and a protected servo (and amp) rail.

| Net | Source | Loads |
| --- | --- | --- |
| **+5V** | USB-C **VBUS** → 3 A PPTC fuse | ESP32 **5V**, 5 V indicator, eFuse input |
| **SERVO_5V** | TPS259571 eFuse out of **+5V** (~2 A via `R14`) | Servo header 5 V pins, bulk capacitor; amp supply via net tie |
| **AUDIO_5V** | Net-tied from **SERVO_5V** (not raw **+5V**) | MAX98357A **Vin** |
| **3V3** | ESP32 onboard LDO, from the 5 V input | ESP32 core/GPIO, PCA9685 **VCC** / **VDD**, OLED **VCC**, I2C pull-ups |
| **GND** | Board USB-C GND + ESP32 GND | Everything |

ESP32 internally runs at 3.3 V logic. Servo power **does not** pass through the ESP32 3.3 V regulator. On the main control board: **+5V** feeds the module **5V** pad; **SERVO_5V** feeds the servo plugs; PCA9685 **VDD** ← **3V3**. The chip has no package “V+” pin — servo 5 V is a board distribution net to the connector (same idea as Adafruit breakout **V+**). The advanced breakout harness draws equivalent nets without the board eFuse — [wiring.md](wiring.md).

> [!WARNING]
> Never power the servos from the ESP32 3.3 V regulator.

Waveshare documents the C3-Zero LDO as ME6217C33M5G (hundreds of mA class). That is enough for logic + OLED + PCA9685 digital. It is **not** a servo supply.

Multi-servo stall can hit the eFuse’s ~2 A limit before the 3 A resettable fuse trips. Use a **5 V / ≥ 2 A** supply; expect occasional **SERVO_5V** (and amp) cutouts under heavy load, then auto-retry.

## Servo current (worst case)

Datasheet stall currents for PowerHD HD-1370A:

| Voltage | Per servo stall | × 5 servos |
| --- | --- | --- |
| 4.8 V | ~260 mA | **≈ 1.3 A** |
| 6.0 V | ~320 mA | **≈ 1.6 A** |

Robot rail is nominally **5 V**, so expect something between those two if several HD-1370A servos stall or start together.

**Tower Pro SG90** (recommended) is larger and typically stalls harder. Same **5 V / ≥ 2 A** floor; give more margin if several SG90s move while audio plays. Do not treat the HD-1370A milliamp table as an SG90 budget.

This **excludes**:

- ESP32 (Wi-Fi TX peaks)
- OLED
- PCA9685 logic
- MAX98357A + speaker peaks
- USB host current shared with programming when flashing over the same cable

## USB supply

Power and data enter on the **main control board USB-C** (one cable). Nets: VBUS → fuse → **+5V**, GND, D− → GPIO18, D+ → GPIO19. Servos and the amp sit behind the eFuse on **SERVO_5V** / **AUDIO_5V**. Details: [interfaces.md](interfaces.md).

Two 5.1 kΩ CC resistors on the board mark it as a USB device. The charger decides how much current arrives. Use a **5 V / ≥ 2 A** source, with extra margin if several servos move **while audio plays**. The connector is **not** USB-PD voltage conversion. Feed it 5 V USB.

Five HD-1370A servos at stall (~1.3 A @ 4.8 V) plus the rest of the robot leaves little safety margin on a 1.5 A port. SG90 stall is typically higher still.

Leave the ESP32-C3-Zero **onboard USB-C unused** when the robot is assembled so two 5 V sources cannot fight on the same rail. That one cable supplies robot power and programming / serial CDC (`ARDUINO_USB_MODE=1`, `ARDUINO_USB_CDC_ON_BOOT=1`, monitor 115200).

Advanced path (Adafruit 5993, CC resistors advertising up to ~1.5 A): [wiring.md](wiring.md#usb-connector-5993).

## Insufficient-power symptoms

If the rail sags under servo or audio load:

- ESP32 resets / brownouts
- Servo jitter or weak motion
- OLED glitches or blanking
- Audio noise / dropouts
- Unstable I2C (NACKs, PCA9685 or OLED “not found” after motion starts)
- Resets **specifically when multiple servos start moving**

Bring-up test turns all five servos together — that is a power-stress moment.

Related: [main-control-board.md](main-control-board.md), [components.md](components.md), [interfaces.md](interfaces.md). Advanced harness: [wiring.md](wiring.md).

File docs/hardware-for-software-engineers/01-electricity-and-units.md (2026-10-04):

# Electricity and units

Before you touch a wire, you need a shared vocabulary. Hardware docs throw around V, A, Ω, and GND like everyone took a circuits class. You didn't — that's fine. This chapter gets you to "I know what could kill my board." Every embedded project has power rails and a common ground; Tiny Engineer is a clear example of **two voltage domains** on one USB cable.

---

## Voltage, current, resistance, power

Four quantities. You'll see them on every datasheet.

| Quantity | Unit | What it means (intuition) |
| --- | --- | --- |
| **Voltage (V)** | Volts | Electrical "pressure" — how hard electrons are being pushed |
| **Current (I)** | Amperes (amps) | Flow rate — how many electrons per second |
| **Resistance (R)** | Ohms (Ω) | How much something resists flow |
| **Power (P)** | Watts (W) | Energy used per second — P ≈ V × I |

> **If you've written backend code…** Voltage is like request pressure on a queue. Current is throughput. Resistance is backpressure. Power is your AWS bill when both spike at once.

**Ohm's law** (you don't need to derive it): V = I × R. If you push harder (more V) through the same resistance, more current flows. Thin wire = more R = less I for the same V.

---

## DC vs AC

**DC (direct current):** voltage stays one way, like a battery. Tiny Engineer runs on **5 V DC** from USB.

**AC (alternating current):** voltage flips direction — wall outlets, 50/60 Hz. Not relevant inside the robot except that your USB charger converts AC to DC before the robot ever sees it.

---

## What "ground" (GND) actually is

GND is not a magical sink into the earth. It's a **shared reference point** that every device agrees is "zero volts."

All signals are measured *relative to GND*. If two boards don't share GND, their "high" and "low" mean nothing to each other — like two services with no common schema.

**Rule:** Connect all GND pins together. One common ground net for the whole robot.

---

## Series and parallel (just enough)

**Series:** components in a chain — same current flows through all of them.

**Parallel:** components side by side — same voltage across each branch; current splits.

Your five servos are **parallel** on the 5 V rail: each gets 5 V, and current adds up. That's why five servos can pull ~1.3 A together and overwhelm a weak USB port.

---

## Shorts, reversed polarity, and smoke

Three ways beginners destroy boards. Each is a **wiring mistake**, not a firmware bug — the code may never run.

### Short circuit — power wired straight to ground

**What it is:** `+5V` and `GND` connected with **almost no resistance** between them — a bare wire, a loose strand, a metal tool, a solder bridge.

**What happens:** Current spikes (Ohm's law: low R → huge I). Wires heat. USB port or regulator shuts off — or something burns. The chip may die instantly.

**What it looks like:** Instant. Sometimes smell. Board never boots. Multimeter beep between 5V and GND *before* power-on = stop and fix wiring.

> **Software analogy:** Like routing all traffic to `/dev/null` with infinite concurrency — the system doesn't degrade gracefully; something upstream trips hard.

**Common causes while wiring:** twisted red/black leads, frayed insulation, screwdriver slip, VCC accidentally tied to GND on a breakout.

### Reversed polarity — + and − swapped

**What it is:** Power connected **backwards** — positive where ground should be, ground where positive should be.

**What happens:** Depends on the board. Some breakouts have protection diodes; many don't. Best case: nothing until you fix it. Worst case: dead regulator, dead MCU, dead module.

**Rule:** Match labels on the diagram (`5V`, `VCC`, `Vin`, `GND`). Red-ish often means positive; black/brown often means ground — **verify**, don't guess from habit alone.

> **Don't "test" reversal on purpose.** Fix orientation before first power-on.

### Logic overvoltage — 5 V on a 3.3 V GPIO pin

**What it is:** Driving **5 V into an ESP32 GPIO** that only tolerates **3.3 V**. Different from powering the whole board at 5 V through its proper **5V** input pad (that path goes through the onboard regulator).

**What happens:** Input protection may clamp once; repeated or sustained overvoltage **damages the pin or the chip**. Behavior becomes erratic; pin may die silently.

**On Tiny Engineer:** I2C, I2S, and servo **signal** lines are 3.3 V logic. Servo **motor power** is 5 V on the red wire — that goes to PCA9685 **V+**, not to an ESP32 GPIO.

> **Software analogy:** Sending a payload the parser never validated — undefined behavior, often permanent. No try/catch on the silicon.

### Quick reference

| Mistake | You literally did | Typical result |
| --- | --- | --- |
| **Short** | Connected +5V to GND directly | Huge current, heat, dead supply path or board |
| **Reversed polarity** | Swapped power + and − on a module | Dead module or MCU — may be instant |
| **Logic overvoltage** | 5 V signal into ESP32 GPIO / 3.3 V input | Damaged pin or chip — flaky then dead |

**Before first power-on:** visual check, then continuity test (power **off**) — no beep between 5V and GND; every module's GND tied together. Assembly checks: [wiring.md](../hardware/wiring.md).

---

## 3.3 V, 5 V, and ones and zeros

In code you think in **bits**: `0` and `1`, `true` and `false`, `LOW` and `HIGH`. On a GPIO pin that is **not abstract** — the chip **holds the wire at a voltage** relative to GND:

| Logic (firmware) | Typical voltage on ESP32 pin | Meaning |
| --- | --- | --- |
| **0** / `LOW` / `false` | ~**0 V** (near GND) | "Pull the line down" |
| **1** / `HIGH` / `true` | ~**3.3 V** | "Pull the line up" |

So **3.3 V is the "one" voltage** on this robot's logic wires. A **zero** is not a separate negative voltage — it's "close enough to ground."

> **If you've written backend code…** GND is 0.0; a logic **1** is ~3.3 — like a boolean with a defined numeric encoding on the wire. I2C and I2S don't send JSON; they toggle and stream voltages that the other chip interprets as bits.

### Two different jobs — don't confuse them

| | **3.3 V (logic domain)** | **5 V (power domain)** |
| --- | --- | --- |
| **Role** | Encode **0s and 1s**; run logic chips at their rated voltage | **Deliver energy** — motors, audio amp, board power input |
| **On Tiny Engineer** | ESP32 GPIO, I2C (SDA/SCL), I2S (BCLK/LRC/DIN), servo **signal** wires, **VCC** on PCA9685/OLED | Servo **motor** power (red wire → PCA9685 **V+**), MAX98357A **Vin**, ESP32 **5V** input pad |
| **Current** | Milliamps per pin / tens of mA on a **VCC** rail | Up to **~1.5 A** when servos stall |

**VCC** on a breakout (3.3 V) = "power this chip's brain so it can read and drive ones and zeros." It is **not** the same net as the 5 V that spins a servo.

**5V** on the ESP32 board = "feed the module" — an onboard **LDO** drops that to 3.3 V so the chip's core and GPIO speak the right logic levels.

### What goes wrong if you mix them up

- **5 V on a GPIO / I2C / I2S line** — you're forcing a **"one" louder than the chip allows** (~3.3 V max on ESP32). Damage. See **Logic overvoltage** above.
- **Servo motor power from 3.3 V** — the line can't supply enough **current** to move metal; brownout or dead regulator. Signal wire at 3.3 V PWM is fine; **power** wire needs 5 V.

When you read `digitalWrite(pin, HIGH)` in firmware, picture **~3.3 V on that pin**. When you read a schematic's **3V3** net, picture **the rail that defines what a "one" looks like** for every chip tied to it.

---

## Two voltage domains (the idea)

Real boards rarely run everything at one voltage. You'll see:

- A **power rail** (often 5 V) for things that need muscle — motors, amplifiers
- A **logic rail** (3.3 V) where **ones and zeros live** — GPIO, I2C, I2S, chip **VCC**

They share GND (that's your **zero**). They do **not** share the same positive rail unless a regulator explicitly converts between them.

---

## In Tiny Engineer

This robot is a textbook example of **two domains on one USB cable**.

```mermaid
flowchart TB
  USB["USB 5V"]
  subgraph fiveV [5V domain]
    ESP5[ESP32 5V in]
    PCApwr[PCA9685 5V and V+]
    MAXvin[MAX98357A Vin]
    SERVOS[Servo motors]
  end
  subgraph threeV [3.3V logic domain]
    ESPcore[ESP32 GPIO and core]
    PCAlogic[PCA9685 VCC]
    OLED[OLED VCC]
  end
  USB --> fiveV
  ESP5 --> ESPcore
  ESPcore --> threeV
  PCApwr --> SERVOS
```

**5 V domain** — USB comes in through the main control board USB-C (advanced path: Adafruit 5993 — [wiring.md](../hardware/wiring.md#usb-connector-5993)) and feeds:
- ESP32 **5V** input (then an onboard LDO drops to 3.3 V for the chip)
- PCA9685 **5V** and **V+** (servo motor power)
- MAX98357A **Vin** (audio amp)

**3.3 V domain** — the ESP32's LDO generates the rail where **logic 1 = ~3.3 V** and **logic 0 = ~0 V**:
- ESP32 core and GPIO (your `HIGH` / `LOW` in code)
- PCA9685 **VCC** (chip logic + I2C — reads 0/1 on SDA/SCL)
- OLED **VCC** (display logic on the same I2C bus)

### The mistake that costs boards

The PCA9685 has **VCC** (3.3 V logic) and **V+** (5 V servo power). They must stay **separate**. Beginners jumper them because both say "power." Don't. You feed motor current into logic circuits or starve servos of voltage.

### Never power servos from 3.3 V

Five PowerHD HD-1370A servos at stall draw on the order of **1.3–1.6 A**. **SG90** (recommended) is larger and typically stalls harder. The ESP32's LDO is rated for hundreds of mA of *logic*. Plug servos into 3.3 V and you get brownout, reset, or a dead regulator. Servos get 5 V via PCA9685 **V+**; the signal wire is 3.3 V PWM from the driver — that's fine.

### Common GND

Every module — ESP32, PCA9685, OLED, amp, servos — ties GND to the same net. Power without shared GND is like deploying microservices that can't reach each other's network.

Full stall math and symptom tables: [power.md](../hardware/power.md).

---

**Next:** [Microcontrollers and ESP32](02-microcontrollers-and-esp32.md)

**Reference:** [hardware/power.md](../hardware/power.md) · [hardware/main-control-board.md](../hardware/main-control-board.md) · [hardware/wiring.md](../hardware/wiring.md)

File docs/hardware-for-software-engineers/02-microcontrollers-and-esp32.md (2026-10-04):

# Microcontrollers and ESP32

Your laptop runs Linux, Chrome, and seventeen Slack notifications. A microcontroller runs *one program*, forever, with no OS you recognize. That gap — between "real computer" and "chip that drives GPIO" — is where most software engineers stall. This chapter closes it. Tiny Engineer uses an **ESP32-C3** as its instance; the ideas apply to Arduino, STM32, and most hobby boards.

---

## MCU vs SBC vs your laptop

| | Microcontroller (MCU) | Single-board computer (SBC) | Laptop |
| --- | --- | --- | --- |
| Examples | ESP32, Arduino, STM32 | Raspberry Pi, BeagleBone | What you're reading this on |
| OS | Bare-metal or RTOS; often "Arduino" | Full Linux | Full OS |
| Boot time | Milliseconds | Seconds | Minutes if updates pending |
| GPIO pins | Yes, direct | Yes, but often through OS layers | Basically no |
| Real-time I/O | Designed for it | Possible, awkward | Not the point |
| Power | Milliwatts to low watts | Watts | Tens of watts |

Tiny Engineer needs Wi-Fi, five servos, a display, and audio on a desk robot budget. An MCU with built-in radio fits. A Pi would work but adds OS overhead, boot time, and power for no gain here.

---

## What firmware is

**Firmware** is the program stored in flash on the chip. It runs on boot. There's no `git pull` on the device — you **build** on your computer and **upload** (flash) the binary over USB.

> **If you've written backend code…** Flashing firmware is deploying a single static binary to a device with no package manager. Serial monitor is `stdout`. There's no SSH — you re-flash or use HTTP once Wi-Fi works.

**Flash** = non-volatile storage (survives power-off). Holds your program and, on this project, LittleFS files (WAV sounds).

**RAM** = working memory. Much smaller than flash. Gone on reboot.

---

## GPIO — the hardware API

**GPIO** (General Purpose Input/Output) pins are wires the firmware controls or reads. On the wire that is literally **zeros and ones** as voltages (see [Ch. 01](01-electricity-and-units.md)):

- **Output HIGH / 1** ≈ 3.3 V on that pin (on ESP32)
- **Output LOW / 0** ≈ 0 V (GND)
- **Input** — read whether the other side is holding the line high or low

Blink an LED? Firmware toggles one pin between 0 and 1. Same idea scales up: **communication protocols are patterns of zeros and ones on one or more pins over time** — serial (UART), I2C, SPI, I2S, even USB on this chip. Libraries hide the bit timing; underneath it's still GPIO-level signaling.

You don't get unlimited pins. Each pin might be reserved for flash, USB, or boot strapping. Scarcity is real — see [pinout.md](../hardware/pinout.md) for the full map.

---

## Boot, reset, and upload

**RESET** — reboots the chip (like killing and restarting a process).

**BOOT** — strapping pin; hold during reset to enter serial upload mode if auto-reset fails.

**Upload** — PlatformIO sends firmware over USB. On ESP32-C3, that's **native USB** on specific GPIO pins (not a separate USB-UART chip).

If upload fails: try another cable (data, not charge-only), another port, hold BOOT, check drivers. Details in [flash.md](../flash.md).

---

## What "Arduino on ESP32" means

This project uses **PlatformIO** with the **Arduino framework** for ESP32. You get `setup()` / `loop()`, familiar libraries (`Wire` for I2C, etc.), and Espressif's Wi-Fi stack underneath.

You're not writing bare-metal RISC-V assembly. You're writing C++ that compiles to a binary the chip runs directly. `platformio.ini` picks the board target and libraries.

---

## ESP32 family (just enough context)

Espressif makes many ESP32 variants. Tiny Engineer uses **ESP32-C3**:

- **RISC-V** single-core (not the older dual-core Xtensa ESP32)
- **Wi-Fi 2.4 GHz only** — no 5 GHz; your router must expose 2.4 GHz for setup
- **BLE** exists on the silicon; this project's firmware doesn't use it
- Native **USB** — no external CP2102 required when wired correctly

---

## In Tiny Engineer

### The board: Waveshare ESP32-C3-Zero

Not a generic breadboard devkit. It's a compact module with castellated edges, a ceramic antenna, and an onboard RGB LED.

**PlatformIO naming trap:** `board = esp32-c3-devkitm-1` in `platformio.ini` is a **build target name**, not the physical board in your hand. The physical board is the C3-Zero. Same chip, different pin breakout — the project's [pinout.md](../hardware/pinout.md) and [components.md](../hardware/components.md) describe *this* board.

### What the ESP32 does here

| Job | How |
| --- | --- |
| Wi-Fi + HTTP API | Agent integration, web UI, `/anim`, `/test/*` |
| I2C master | Talks to PCA9685 (servos) and OLED (display) |
| I2S master | Streams audio samples to MAX98357A |
| Status RGB | Onboard WS2812 on GPIO10 — boot green, anim white, error red |
| "Sensor" | On-die CPU temperature in `/health` — that's it, no IMU |
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

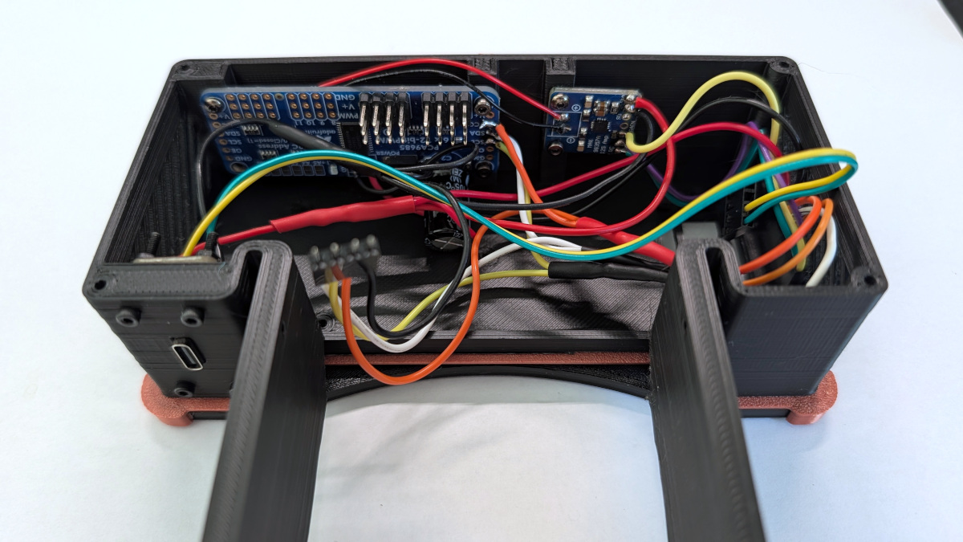
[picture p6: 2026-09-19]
docs/3d/assembly_visuals/electronics_1b.jpg

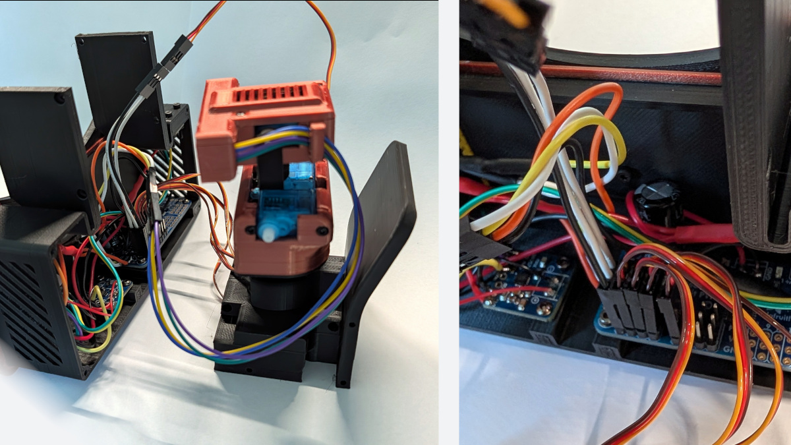
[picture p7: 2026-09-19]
docs/3d/assembly_visuals/electronics_3b.jpg

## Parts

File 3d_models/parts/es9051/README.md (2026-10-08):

# EMAX ES9051

- `servo_id`: es9051
- `servo_body_width`: 20.1 mm
- `servo_body_height`: 15 mm
- `servo_mount_width`: 4.6 mm
- `servo_mount_thickness`: 1.1 mm
- `servo_gearbox_height`: 4.1 mm
- `servo_gearbox_padding`: 8 mm
- `servo_shaft_housing_height`: 3.6 mm
- `servo_shaft_position`: 4.4 mm
- `servo_shaft_length`: 3 mm
- `servo_shaft_radius`: 1.93 mm
- `servo_body_depth`: 8.8 mm
- `servo_mount_hole_radius`: 1.2 mm
- `servo_mount_hole_depth_offset`: 0 mm
- `servo_mount_hole_width_offset`: 0.1 mm

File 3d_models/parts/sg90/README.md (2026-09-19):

# Tower Pro SG90

- `servo_id`: sg90
- `servo_body_width`: 22.7 mm
- `servo_body_height`: 17 mm
- `servo_mount_width`: 4.8 mm
- `servo_mount_thickness`: 2.4 mm
- `servo_gearbox_height`: 4.4 mm
- `servo_gearbox_padding`: 7.8 mm
- `servo_shaft_housing_height`: 3.5 mm
- `servo_shaft_position`: 5.8 mm
- `servo_shaft_length`: 3.3 mm
- `servo_shaft_radius`: 2.4 mm
- `servo_body_depth`: 12.2 mm
- `servo_mount_hole_radius`: 1.4 mm
- `servo_mount_hole_depth_offset`: 0 mm
- `servo_mount_hole_width_offset`: 0.07 mm

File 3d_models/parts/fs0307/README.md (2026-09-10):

# Feetech FS0307

- `servo_id`: fs0307
- `servo_body_width`: 20 mm
- `servo_body_height`: 13 mm
- `servo_mount_width`: 3.8 mm
- `servo_mount_thickness`: 1 mm
- `servo_gearbox_height`: 3.7 mm
- `servo_gearbox_padding`: 6.5 mm
- `servo_shaft_housing_height`: 4 mm
- `servo_shaft_position`: 4.5 mm
- `servo_shaft_length`: 3.3 mm
- `servo_shaft_radius`: 1.83 mm
- `servo_body_depth`: 8.6 mm
- `servo_mount_hole_radius`: 1 mm
- `servo_mount_hole_depth_offset`: 0 mm
- `servo_mount_hole_width_offset`: 0 mm

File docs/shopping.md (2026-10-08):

# Shopping list

Buy this before you print or connect. Electrical spec (voltages, limits, pin notes): [hardware/components.md](hardware/components.md). Screw lengths in assembly steps: [3d_models/README.md → Screws](../3d_models/README.md#screws). Build order: [getting-started.md](getting-started.md).

## Servo size (pick first)

> **First build:** buy **five Tower Pro SG90** (or equivalent 9 g analog micros). Print [`3d_models/parts/sg90/`](../3d_models/parts/sg90/3mf/). Do **not** open Fusion.

Servo size sets the size of the **whole robot**. Buy five of **one** model, then print (or order) the matching `parts/{servo_id}/` folder.

| Choice | When | Print folder |
| --- | --- | --- |
| **Tower Pro SG90** (recommended) | Default. Bigger desk — electronics are easier to fit | [`parts/sg90/`](../3d_models/parts/sg90/3mf/) |
| **Feetech FS0307** | Compact robot | [`parts/fs0307/`](../3d_models/parts/fs0307/3mf/) |
| **EMAX ES9051** | Compact — similar footprint to FS0307, slightly taller | [`parts/es9051/`](../3d_models/parts/es9051/3mf/) |
| **PowerHD HD-1370A** | Backward compatibility only — skip for a new build | [`parts/hd1370a/`](../3d_models/parts/hd1370a/3mf/) |

Non-preset servo: measure it, add a preset, export parts — [parametric design](3d/parametric-design.md).

## Electronics

The default build uses the **main control board**. PCA9685, the audio amp, and USB-C are on that PCB. You plug in the ESP32, OLED, five servos, and the speaker.

Order the open-source board from any fab: [hardware/order-main-control-board.md](hardware/order-main-control-board.md). Connect it: [hardware/main-control-board.md](hardware/main-control-board.md). A cheaper assembled batch may show up later: [discussion #50](https://github.com/jamro/tiny-engineer/discussions/50). Fab lead time is part of ordering the board.

### Default cart

| Part | Qty | Link / notes |
| --- | --- | --- |
| Tiny Engineer main control board | 1 | KiCad in [`hardware/boards/main-control-board/`](../hardware/boards/main-control-board/) ([CERN-OHL-S](../3d_models/LICENSE)). Order: [hardware/order-main-control-board.md](hardware/order-main-control-board.md). |
| Waveshare ESP32-C3-Zero | 1 | https://docs.waveshare.com/ESP32-C3-Zero |
| Tower Pro SG90 (or equivalent 9 g analog micro) | 5 | Widely available hobby servo — no single canonical SKU |
| [Adafruit Mini Oval Speaker - 8 Ohm 1 Watt](https://www.adafruit.com/product/3923) | 1 | https://www.adafruit.com/product/3923 |
| [Waveshare 0.91inch OLED Module](https://www.waveshare.com/0.91inch-oled-module.htm) (SSD1306, 128×32, I2C) | 1 | https://www.waveshare.com/0.91inch-oled-module.htm |

Compact build: swap the five SG90 for **Feetech FS0307** or **EMAX ES9051** (same qty). Do not mix models.

The board already includes the PCA9685, the MAX98357A, and USB-C.

### Advanced: extra modules

Use separate breakouts when you want modules the main control board does not support. Same firmware and printed Desk. More soldering and more boards in the cavity. Wiring: [hardware/wiring.md](hardware/wiring.md). Desk mounting: [3d/assembly-modular.md](3d/assembly-modular.md).

| Part | Qty | Link |
| --- | --- | --- |
| Adafruit PCA9685 16-channel PWM servo driver | 1 | https://www.adafruit.com/product/815 |
| MAX98357A I2S class-D mono amplifier | 1 | https://www.aliexpress.us/item/3256805196806369.html |
| Adafruit 5993 USB-C breakout | 1 | https://www.adafruit.com/product/5993 |

These three replace the main control board. You still buy the ESP32, servos, speaker, and OLED from the default cart.

### Fasteners

M2 thread-forming (self-tapping) screws for plastic, **pan-head or button-head**. Qty below is the shopping list; per-step placement stays in [3d_models/README.md → Screws](../3d_models/README.md#screws).

| Item | Qty |
| --- | --- |
| M2×4 mm | 8 |
| M2×8 mm | 27 |
| M2×16 mm | 15 |
| M2 nuts | 6 |
| Servo bag screws | 5 (come with the servos) |

The six `BottomCover` screws are included in the M2×8 total. Their heads must be at most **4.0 mm diameter × 2.0 mm high** to fit the recessed pockets.

An M2 assortment covering **M2×4–M2×16** is the easy path. Nearby lengths often work; test-fit if you substitute.

### Power and cables

| Item | Qty | Notes |
| --- | --- | --- |
| **5 V / ≥2 A** USB supply (or a host that can actually deliver that) | 1 | Five stalled servos plus Wi-Fi and audio need headroom. A 1 A phone charger will brown out. |
| USB-C **data** cable | 1 | Charge-only cables fail flash and serial. |

### Printed parts

Home printer: **PLA** or **PETG**, testers first — [3d_models/README.md](../3d_models/README.md). No printer: [order printed parts](3d/order-parts.md).

## Next

Return to the [getting-started](getting-started.md) checklist ([§1 Shop](getting-started.md#1-shop) done). Then print or order.

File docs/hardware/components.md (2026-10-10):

# Hardware inventory

Buyers: start at [shopping.md](../shopping.md). The default build has the PCA9685, the MAX98357A, and USB-C on the [main control board](main-control-board.md). This page is the electrical spec for those chips and the plug-in modules (ESP32, servos, OLED, speaker). Breakout SKUs are the advanced path — [wiring.md](wiring.md).

Selected hardware only. Substituting a part means updating this file, [pinout.md](pinout.md), and either the board design or [wiring.md](wiring.md). Servo *model* may be any preset in [`servos.json`](../../3d_models/fusion/TinyEngineerTools/servos.json) if the printed parts match — [parametric design](../3d/parametric-design.md).

Constants cited below match [`include/pins.h`](../../include/pins.h).

## Product links

| Part | Link |
| --- | --- |
| Waveshare ESP32-C3-Zero | https://docs.waveshare.com/ESP32-C3-Zero |
| Adafruit PCA9685 breakout (advanced path) | https://www.adafruit.com/product/815 |
| Tower Pro SG90 (or equivalent) | Widely available hobby servo — no single canonical SKU |
| Feetech FS0307 | See vendor listing for FS0307 analog micro |
| PowerHD HD-1370A (backward compatibility) | https://www.chd.hk/Product_Detail.aspx?id=30 |
| MAX98357A breakout (advanced path) | https://www.aliexpress.us/item/3256805196806369.html |
| [Adafruit Mini Oval Speaker - 8 Ohm 1 Watt](https://www.adafruit.com/product/3923) | https://www.adafruit.com/product/3923 |
| Waveshare 0.91inch OLED Module | https://www.waveshare.com/0.91inch-oled-module.htm |
| Adafruit 5993 USB-C breakout (advanced path) | https://www.adafruit.com/product/5993 |

## Waveshare ESP32-C3-Zero

| Field | Value |
| --- | --- |
| Exact model | Waveshare ESP32-C3-Zero (ESP32-C3FH4) |
| Quantity | 1 |
| Purpose | Main controller: I2C, I2S, USB CDC, Wi-Fi, onboard RGB |
| Operating voltage | GPIO **3.3 V**. External power on the **5V** pad: 3.7–6 V (robot uses the +5V rail) |
| Logic | **3.3 V only** — do not drive 5 V into GPIO |
| Radio | Wi-Fi 2.4 GHz (product use). BLE present on silicon but **out of scope** |
| USB | Native USB on GPIO18/19 — reached via the main control board USB-C (onboard USB-C unused when assembled). Advanced path: Adafruit 5993 — [wiring.md](wiring.md#usb-connector-5993) |
| Flash | 4 MB stacked flash on GPIO12–GPIO17 (those GPIOs are **not exposed**) |
| Onboard RGB | WS2812 on **GPIO10** |
| Firmware notes | Boot: dim green status. Animations: white (typing/reading/thinking/talking/welcome/ring/wakeup), pulsing red (attention/error/dead), solid red (abort), off (idle/sleep). 1 s fade between non-pulse states. Fatal init errors: hang and blink red (1 = PCA9685, 2 = I2S). See [blink codes](testing.md#boot-failure-blink-codes) and [`docs/api.md`](../api.md#rgb-led) |
| BOOT | Button / strapping on **GPIO9** |
| RESET | Separate RESET button (CHIP_EN), not a GPIO |
| UART0 silkscreen | TX = GPIO21, RX = GPIO20 |
| USB D− / D+ | GPIO18 / GPIO19 (native USB) |
| 3V3 regulator | Onboard LDO (Waveshare: ME6217C33M5G). For **logic loads only** |
| Important pins | See [pinout.md](pinout.md) |
| Limits | Do not power servos from **3V3**. Do not cover the ceramic antenna with metal, PCB, or plastic. |
| Firmware note | PlatformIO `board = esp32-c3-devkitm-1` is a **build target**, not the physical module. Physical board is C3-Zero. |

## Adafruit PCA9685 16-channel PWM servo driver

| Field | Value |
| --- | --- |
| Exact model | PCA9685 on the main control board. Advanced path: Adafruit 16-Channel 12-bit PWM/Servo Driver breakout |
| Quantity | 1 |
| Purpose | Independent 50 Hz servo PWM so ESP32 timing is not the PWM source |
| Operating voltage | **VCC** (logic): 3.3 V from ESP32 **3V3**. **V+** (servos): +5V rail |
| Interface | I2C |
| Address | `0x40` (`PCA9685_ADDRESS` in firmware). A0–A5 pads can change this |
| PWM | 12-bit, firmware `setPWMFreq(50)` |
| Important pins | As drawn: **5V** (servo-rail in), **V+** (to servo 5V), **VCC** (3V3 logic), **GND**, **SDA**, **SCL**, **PWM**, **OE** (GP5, active LOW) |
| Channels used | 0–4 (five servos). 5–15 unused |
| Limits | **V+** and **VCC** must stay separate. Do not jumper servo power onto logic VCC on this robot |
| Firmware note | Detection at `0x40` is a **hard fail** in the bring-up test |

## Analog micro servos (qty 5)

Five analog micro servos drive the joints (Head / Neck / L hand / R hand / Body — [robot-movement.md](../robot-movement.md)). Buy **five of one model**. Print the matching `parts/{servo_id}/3mf/` folder. Which size to pick: [parametric design](../3d/parametric-design.md).

Shared for every preset:

| Field | Value |
| --- | --- |
| Quantity | 5 (one model) |
| Operating voltage | Robot: **+5V** via PCA9685 **V+** |
| Interface | Analog PWM, ~50 Hz. Signal is 3.3 V from PCA9685 — acceptable for this servo class |
| Pulse | Neutral ~1500 µs. Firmware window **800–2200 µs** (`SERVO_MIN_US` / `SERVO_MAX_US`) |
| Important pins | SIG, +5V, GND (JR-style 3-wire) |

> [!WARNING]
> Never power the servos from the ESP32 3.3 V regulator.

Firmware uses **per-servo safe ranges** in [`include/servos.h`](../../include/servos.h) (`SERVO_SPECS`). Tune after assembly if needed. Do not command full 0–180° / 800–2200 µs on the assembled robot. See [servos.md](servos.md).

### Tower Pro SG90 (recommended)

Easiest to buy. Larger body → larger printed robot; electronics are easier to fit in the desk.

| Field | Value |
| --- | --- |
| Exact model | Tower Pro SG90 analog micro (or equivalent 9 g class) |
| `servo_id` | `sg90` |
| Size | Larger than FS0307 / HD-1370A — see [`servos.json`](../../3d_models/fusion/TinyEngineerTools/servos.json) |

Print [`3d_models/parts/sg90/3mf/`](../../3d_models/parts/sg90/3mf/).

### Feetech FS0307

More compact. Use this if you want a smaller robot that looks tighter on the desk.

| Field | Value |
| --- | --- |
| Exact model | Feetech FS0307 analog micro servo |
| `servo_id` | `fs0307` |

Print [`3d_models/parts/fs0307/3mf/`](../../3d_models/parts/fs0307/3mf/).

### PowerHD HD-1370A (backward compatibility)

Still supported. Not the pick for a new build.

Print [`3d_models/parts/hd1370a/3mf/`](../../3d_models/parts/hd1370a/3mf/).

| Field | Value |
| --- | --- |
| Exact model | PowerHD HD-1370A analog micro servo |
| `servo_id` | `hd1370a` |
| Current (datasheet stall) | ~260 mA @ 4.8 V, ~320 mA @ 6.0 V |
| No-load current | ~110 mA @ 4.8 V, ~120 mA @ 6.0 V |
| Idle current | ~4 mA @ 4.8 V, ~5 mA @ 6.0 V |
| Torque / speed | 0.4 kg·cm / 0.12 s/60° @ 4.8 V; 0.6 kg·cm / 0.10 s/60° @ 6.0 V |
| Size / mass | ~20.2 × 8.5 × 17.6 mm, ~3.7 g |
| Limits | Manufacturer sheet also lists **~130°** travel over 800–2200 µs, while many retailers say 0–180°. Treat 0–180° as **nominal**, not a mechanical guarantee. |

## MAX98357A I2S class-D mono amplifier

| Field | Value |
| --- | --- |
| Exact model | MAX98357A on the main control board (I2S in, speaker out). Advanced path: breakout module |
| Quantity | 1 |
| Purpose | Digital audio → mono speaker. ESP32 never drives the speaker as GPIO PWM |
| Operating voltage | **Vin** 2.5–5.5 V. Drawing: USB **5V** → **Vin** |
| I2S logic | 3.3 V from ESP32 (compatible) |
| Interface | I2S: **BCLK**, **WS/LRC**, **DIN**. No MCLK |
| Sample rates | Chip: 8–96 kHz. Firmware: **22050 Hz**, 16-bit, stereo slot mode |
| Output power (typical) | ~1.8 W into 8 Ω @ 5 V / 10% THD (datasheet-class figure) |
| Important pins | **Vin**, **GND**, **BCLK**, **LRC**, **DIN**, **SPK+**, **SPK-**. Board gain: solder jumper ([board README](../../hardware/boards/main-control-board/README.md)). Breakout **GAIN** / **SD** left unwired (GAIN floating ≈ 9 dB, SD pulled up ≈ left channel) — [wiring.md](wiring.md) |
| Limits | Output is **BTL**. Do not connect SPK- to GND. Do not feed SPK+/SPK- into another amplifier. Do not drive the speaker from ESP32 GPIO |

> [!WARNING]
> MAX98357A SPK- is not ground.

## Speaker

| Field | Value |
| --- | --- |
| Exact model | [Adafruit Mini Oval Speaker - 8 Ohm 1 Watt](https://www.adafruit.com/product/3923) (8 Ω, 1 W mono) |
| Quantity | 1 |
| Purpose | Acoustic output |
| Operating voltage | Not a voltage-rail device — driven by MAX98357A BTL |
| Interface | Two terminals → **SPK+** and **SPK-** |
| Limits | 1 W rated. Amp can theoretically exceed 1 W into 8 Ω at 5 V; keep firmware volume moderate. Never connect either terminal to **GND** |

Speaker wiring is **not** drawn on `docs/wiring/Tiny Engineer.drawio`. Electrical rule is still: speaker ↔ SPK+/SPK- only.

## Waveshare 0.91inch OLED Module (SSD1306, I2C)

| Field | Value |
| --- | --- |
| Exact model | [Waveshare 0.91inch OLED Module](https://www.waveshare.com/0.91inch-oled-module.htm) (SKU 14657). Driver SSD1306, 128×32, I2C |
| Quantity | 1 |
| Purpose | Status / test UI |
| Operating voltage | Module accepts **3.3 V / 5 V**. Robot **VCC** from ESP32 **3V3** (confirmed in [`docs/wiring`](../wiring/Tiny%20Engineer.drawio.png)) |
| Interface | I2C on the shared bus. Pads **VCC**, **GND**, **SDA**, **SCL** |
| Address | **`0x3C`** (`OLED_ADDRESS` in firmware). Alternate 0x3D exists on some modules if the ADDR jumper is changed — not used here |
| Resolution | 128×32 (`OLED_WIDTH` / `OLED_HEIGHT`) |
| Important pins | **VCC**, **GND**, **SDA**, **SCL**. Clock pad on this board is **SCL**. The wiring PNG may still label that net **SCK** (generic clone silkscreen) — same I2C clock, ESP32 **GP1** |
| Firmware notes | `SSD1306_SWITCHCAPVCC`; rotation from `oled_rotate_180` (`setRotation(0)` or `2`). Missing OLED is **non-fatal** in the bring-up test |
| Limits | Robot wiring is **3V3**. Do not hang this module on the servo +5V rail |

## USB-C

Default connector is on the main control board — [power.md](power.md), [main-control-board.md](main-control-board.md). Advanced path: Adafruit 5993 — [wiring.md](wiring.md#usb-connector-5993).

## Mechanical / RF notes for firmware and CAD

- Keep metal and dense plastic **off** the ESP32 ceramic antenna area.
- Servo horns and end stops: start from `SERVO_SPECS` in [`include/servos.h`](../../include/servos.h); tune after installation if needed. Assembled motion stays inside the saved min/max.
- GPIO18/19 are native USB via the main control board USB-C (or the 5993 on the advanced path). Leave them assigned while using USB CDC for flash/serial.

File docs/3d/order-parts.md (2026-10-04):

# Order printed parts (no 3D printer)

No printer at home? You can still get the printed set from a third-party 3D-printing service, then return to the [getting-started](../getting-started.md) checklist. Mechanical joins: [assembly.md](assembly.md).

Orders are at your own risk. Fit and finish can vary by provider and by design revision — especially on development builds there may be bugs — and we cannot guarantee every part will match every time.

## Provider

Any FDM bureau that accepts STL or STEP can work. **[PCBWay 3D printing](https://www.pcbway.com/rapid-prototyping/3d-printing/)** is one example that was [partially tested](https://github.com/jamro/tiny-engineer/issues/9).

## Which files to upload

1. Pick the servo folder that matches the servos you bought: `3d_models/parts/<servo_id>/` ([which servo](../shopping.md)).
2. Prefer files under **`stl/`** (widely accepted). Use **`step/`** if the provider prefers CAD. **`3mf/`** is mainly for home slicers.
3. Upload these **three** aggregates only — not the full individual-part inventory. They group pieces meant for the same material / color:

| File | Role |
| --- | --- |
| `PartsSetA.stl` (or `.step`) | Originally silk copper; customize the color if you like |
| `PartsSetB.stl` (or `.step`) | Originally black, including `BottomCover` and the updated `Chair`; customize the color if you like |
| `LampDiffuser.stl` (or `.step`) | White or translucent. Intentionally thin so light passes through; may fail the provider’s minimum wall-thickness check — expect to accept a wall-thickness / damage-risk disclaimer if asked |

The largest black aggregate (SG90) is approximately **235 × 332 mm**. Services can arrange the parts for their machines; on a smaller home print bed, use the individual files instead.

## Settings used in the PCBWay test

Starting point (adjust if your provider’s options differ):

| Setting | Value |
| --- | --- |
| Process | 3D printing / **PLA** (PETG should work; other materials not tested here) |
| Colors | Black / Silk Copper / White |
| Infill | **20%** |
| Threads and tapped holes | **No** |
| Inserts | **No** |

## How to place the order

UI labels change; follow the outcomes, not exact button names. The flow below matches a typical PCBWay-style quote.

1. Create or sign in to an account on the provider’s **3D printing** quote page (not PCB or CNC).
2. Start a new **3D printing / FDM** quote.
3. Upload the three files from the matching `stl/` (or `step/`) folder: `PartsSetA`, `PartsSetB`, `LampDiffuser`. Confirm units are **mm** if asked.
4. For each file, set material (PLA or PETG), color (copper-ish / black / white-or-translucent), **20%** infill, no threads, no inserts.
5. For `LampDiffuser`, if the provider flags thin walls, accept the wall-thickness risk option (wording varies) so the quote can proceed.
6. Review the quote. Printing cost and shipping are separate — shipping can dominate for a single set.
7. Submit the request, wait for technical review / approval, pay, then track shipment.
8. When the parts arrive, dry-fit the servos and M2 screws before full assembly. If you notice that the holes for the screws are too loose, you can gently wrap a small piece of tape (for example, masking tape or electrical tape) around the screw, or place a tiny piece of paper inside the hole before inserting the screw. This will help the screw grip better. Make sure everything fits as expected before final assembly.

## Next steps

Return to the [getting-started](../getting-started.md) checklist ([§2 Print or order](../getting-started.md#2-print-or-order) done). Next on that list is **connect**, then flash, then one assembly run. Part inventory and home-print notes: [3d_models/README.md](../../3d_models/README.md).

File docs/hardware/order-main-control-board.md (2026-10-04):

# Order the main control board

Build the integrated PCB yourself from the open-source KiCad design, then return to the [getting-started](../getting-started.md) checklist. After the boards arrive, connect modules with [main-control-board.md](main-control-board.md).

**Any PCB manufacturer can fabricate this board.** Upload formats, BOM / pick-and-place conventions, assembly options, and part stock differ by fab. If you use someone other than the provider below, adapt the steps to their process and always re-check the bill of materials and part availability before you pay for assembly.

This walkthrough uses **[JLCPCB](https://jlcpcb.com/)** as one common place to order PCB + assembly (PCBA) with LCSC parts. Tiny Engineer has **no partnership** with JLCPCB — the project documents one provider the author chose; you are free to use another.

Orders are at your own risk. Fabrication and assembly can go wrong (missing parts, wrong orientation, stock substitutions). Design revisions — especially early boards — can have bugs. The project cannot guarantee every order yields a working board.

## What you still buy separately

The fab builds the PCB and (if you choose PCBA) the parts soldered onto it. You still need the plug-in modules and the rest of the robot cart: [shopping.md](../shopping.md).

## Prerequisites

- **KiCad 10** (project major — see [pcb.md](../pcb.md))
- KiCad **Fabrication Toolkit** plugin (Plugin and Content Manager → search for Fabrication Toolkit). It exports Gerbers plus JLCPCB-oriented BOM and position files.
- An account at your chosen fab (here: JLCPCB)

## 1. Export manufacturing files from KiCad

1. Open [`hardware/boards/main-control-board/main-control-board.kicad_pro`](../../hardware/boards/main-control-board/main-control-board.kicad_pro).
2. Run **Fabrication Toolkit** so it writes manufacturing outputs under the board folder (typically a `production/` directory).
3. Confirm you have at least:
   - a Gerber **ZIP** (board layers + drills)
   - **`bom.csv`** (bill of materials)
   - **`positions.csv`** (component placement / CPL / pick-and-place)
4. Keep `production/` local — it is gitignored and should not be committed.

UI names for the plugin and export dialog change over time; what matters is those three artifacts.

## 2. Choose how much assembly you want

| Option | Cost / effort | This guide |
| --- | --- | --- |
| **PCB only** | Cheapest. You solder every SMD part yourself. | **Not recommended** for a first order — small SMD work is hard. **Skipped** below. |
| **PCBA, one side (top)** | Good cost compromise. Most electronics are on the front; you solder the ESP32 sockets yourself. | Covered |
| **PCBA, both sides** | Most expensive, most convenient — no soldering needed for the board parts. | Covered |

On **one-side** PCBA, the remaining hand work is soldering **2.54 mm female header** sockets for the Waveshare ESP32-C3-Zero (two 1×9 rows on this design). On **both-sides** PCBA, those headers are assembled for you.

## 3. Place the order (JLCPCB example)

Site menus and labels change. Follow the **outcomes**, not exact button names.

1. Create or sign in to a JLCPCB account and start a new **PCB** order.
2. Upload the Gerber **ZIP** from Fabrication Toolkit.
3. Keep most board options at sensible defaults. As of writing, a typical match for this board is:

   | Setting | Typical choice |
   | --- | --- |
   | Base material | FR-4 |
   | Layers | 2 |
   | Thickness | 1.6 mm |
   | Quantity | Fab minimum if you only need one board (often **5** today) |
   | PCB color | Your choice — colors other than green can cost more |
   | Surface finish | LeadFree HASL (author preference; other finishes are fine if the fab offers them) |

4. **Turn on PCB Assembly.** Leave stencil **off** for this PCBA flow — you do not need a separate stencil when the fab assembles the board.
5. Set assembly options for your path:

   **One side (you solder ESP32 headers later)**

   - PCBA type: **Economic**
   - Assembly side: **Top**
   - Assembly quantity: the fab may let you assemble **fewer** boards than the PCB quantity (for example, assemble 2 of 5). Bare leftovers arrive without parts. Assembling every board costs more but gives working spares; fewer assemblies is a valid way to cut cost.

   **Both sides (fully assembled)**

   - PCBA type: **Standard**
   - Assembly side: **Both sides**
   - For this process the fab may add **edge rails**. Enabling a **depaneling** service is often worth it so you get usable boards without cutting rails yourself.
   - Same note on assembly quantity vs PCB quantity as above.

6. Continue and **review the board layout** in the fab’s viewer. Confirm outline, holes, and copper look right, then proceed.
7. Upload **`bom.csv`** and **`positions.csv`** (the CPL / pick-and-place file), then continue.
8. **Review the bill of materials.** Stock and catalog entries change. Check every line. ESP32 header parts may warn that **multiple catalog items match** — pick the correct one manually. Resolve out-of-stock or wrong parts here (or update the schematic LCSC fields, re-export, and upload again) before you pay.
9. **Review component placement and orientation**, then continue.
10. **Review the cost quote**, complete checkout, and track the shipment.

## 4. When the boards arrive

1. Inspect for missing parts, tombstoned components, or obvious orientation mistakes.
2. **One-side PCBA:** solder the 2.54 mm female headers for the ESP32, then follow [main-control-board.md](main-control-board.md).
3. **Both-sides PCBA:** plug in the ESP32, OLED, servos, and speaker per [main-control-board.md](main-control-board.md) — no board soldering required for those sockets.
4. Return to [getting-started](../getting-started.md) for flash and mechanical assembly.

KiCad sources and electrical notes for contributors: [`hardware/boards/main-control-board/`](../../hardware/boards/main-control-board/). Contribution rules: [pcb.md](../pcb.md). Optional cheaper community batch: [discussion #50](https://github.com/jamro/tiny-engineer/discussions/50).

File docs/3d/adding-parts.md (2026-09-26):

# Adding parts to the CAD

Contributor workflow for new printable geometry in [`3d_models/cad/TinyEngineer.f3d`](../../3d_models/cad/TinyEngineer.f3d). For servo presets and add-in install, see [parametric design](parametric-design.md). For builders printing existing parts, see [`3d_models/README.md`](../../3d_models/README.md).

```mermaid
flowchart TD
  design["Design parametric part"]
  test["Servo Configurator: all presets"]
  layout["Copy into PRINT_LAYOUT"]
  set["Add to PartsSet"]
  export["Parts Exporter: all servos"]
  design --> test --> layout --> set --> export
```

## Design rules

### Source of truth

Edit [`cad/TinyEngineer.f3d`](../../3d_models/cad/TinyEngineer.f3d) only. Never hand-edit `.3mf`, `.stl`, or `.step` exports — those are the release binaries. Change the Fusion source, then re-export.

### Parametric, multi-servo

Drive dimensions from Fusion **user parameters** (servo presets in [`servos.json`](../../3d_models/fusion/TinyEngineerTools/servos.json), or other shared params). Prefer referencing existing geometry (edges, faces, projected sketches) over hard-coded lengths that only fit one servo.

The design must rebuild cleanly for **every** predefined servo. Do not ship a part that only works for SG90.

Do not invent new keys in `servos.json`. Parameter names must already exist as Fusion user parameters in the `.f3d`. Details: [Add a new servo](parametric-design.md#add-a-new-servo).

### Naming

Keep one name end to end:

- Fusion component name
- Direct child under `PRINT_LAYOUT` (what the exporter lists)
- Export basename (`Head.3mf`, …)
- Row in the [`3d_models/README.md`](../../3d_models/README.md) parts table

### Print without supports

Orient and feature the part so FDM can print it **without supports** (no large overhangs past what your bridging/chamfers already handle). The print-ready copy under `PRINT_LAYOUT` must sit on a flat face on the horizontal origin.

### `min_wall_thickness`

Use the Fusion user parameter **`min_wall_thickness`** as the floor for:

- Walls
- Thin horizontal layers / floors

That keeps parts printable at third-party services and on typical 0.4 mm-nozzle FDM setups. Do not go thinner than this parameter.

### M2 / fasteners

Assembly uses **M2** screws that thread directly into printed PLA/PETG. New screw pilots use `screw_thread_diameter` (related: `screw_head_diameter`, `screw_head_height`). Details: [M2 screw holes](parametric-design.md#m2-screw-holes).

- No heat-set inserts unless an intentional, documented exception.
- Prefer existing lengths **M2×4 / M2×8 / M2×16**.
- If a new length is required, update the screw BOM in [`3d_models/README.md`](../../3d_models/README.md) and the cart in [`docs/shopping.md`](../shopping.md).

### Clearance / fit

Design so parts and hardware fit **without sanding** as the happy path. Leave real clearance for servo bodies, horns, and moving links so joints do not bind.

## Timeline discipline

Keep the Fusion timeline readable for other contributors.

1. **One component, one block** — Create the part as a **separate component**. Keep all features that belong to that component (sketches, extrudes, fillets, holes, …) **next to** its creation on the timeline. Do not scatter edits to the same component across distant timeline positions.
2. **Components first, joints later** — Create (or finish) components first. Add joints that lock assembly positions in a **later** timeline section, after component creation.
3. **Same rule under `PRINT_LAYOUT`** — Inside `PRINT_LAYOUT`, define/copy components first; add assembly joints afterward.

## Assembly vs print layout

### Functional assembly

Joint the new component into the main robot assembly so it sits correctly relative to neighbors for all servo presets.

### Print-ready copy (`PRINT_LAYOUT`)

1. **Copy & paste** (not **Paste New**) a ready-to-print instance under the **`PRINT_LAYOUT`** component. Paste keeps the link to the source component so parametric updates stay in sync.
2. Orient it so it lies on the **horizontal origin**, print face down, **no supports**.
3. Lock it to the origin with a **joint** so the export pose stays fixed.
4. Add it to the correct **`PRINT_LAYOUT` / `PartsSet*`** aggregate for its **intended print color** only — do not mix colors in one set. Nest/place it to keep the print bed footprint realistically compact. Lock that placement with a **joint** as well.

`PartsSetA` / `PartsSetB` (and similar) are aggregates of same-color parts for [service orders](order-parts.md). Home printers usually print individual `.3mf` files instead — see [`3d_models/README.md`](../../3d_models/README.md).

## Validate every servo preset

Before you call the part done:

1. Open **Utilities → Add-Ins → TinyEngineer Servo Configurator**.
2. Switch through **all** predefined servos.
3. Confirm the **new part** and the **whole design** update without compute **errors** or **warnings** for any preset.

Fix failures for every preset, not only the one you design against.

## Export

Use **Utilities → Add-Ins → Tiny Engineer Parts Exporter** to export the new part(s) from `PRINT_LAYOUT` into the supported formats for **all** supported servos. Output lands under `3d_models/parts/{servo_id}/` (`3mf/`, `stl/`, `step/`). Details: [parametric design — Parts Exporter](parametric-design.md#tiny-engineer-parts-exporter).

Commit both the updated `.f3d` and the exported meshes/STEP for the affected servos.

## Docs, trademark, and license

After the CAD and exports land:

- **Docs sync** — new stock part → parts table in [`3d_models/README.md`](../../3d_models/README.md); color-group / aggregate change → [order-parts.md](order-parts.md); join-order change → [assembly.md](assembly.md).
- **Trademark** — do not replace or repurpose `AiEmblem` as branding. See [TRADEMARK.md](../../TRADEMARK.md).
- **License** — `cad/` and `parts/` (including under mods) are [CERN-OHL-S-2.0](../../3d_models/LICENSE). When distributing Products based on these designs, keep Source Location accurate per [`3d_models/NOTICE`](../../3d_models/NOTICE).

## Optional mods

Optional elements and community mods do **not** go in the main `cad/` / `parts/` trees as first-class stock parts unless they become core. Overview: [`3d_models/mods/README.md`](../../3d_models/mods/README.md).

Place them under:

```text
3d_models/mods/<mod_name>/
  cad/      # Fusion source for the mod
  parts/   # Exported meshes, same layout idea as 3d_models/parts/
  README.md  # optional but recommended: fit notes, which servo folders exported
```

Mirror the top-level `3d_models` structure (`cad` + `parts`). Keep CERN-OHL-S licensing consistent with [`3d_models/LICENSE`](../../3d_models/LICENSE) when you distribute Products based on these designs. Each mod may include a short `README.md` describing what it fits and which `parts/{servo_id}/` folders were exported.

## Checklist

- [ ] Source of truth: `.f3d` edited; exports re-generated (no hand-edited meshes)
- [ ] Naming: component = `PRINT_LAYOUT` child = export basename = README parts table
- [ ] Parametric (user params / referenced geometry); works for all presets
- [ ] No invented `servos.json` keys (Fusion user params first)
- [ ] Printable without supports; walls/floors ≥ `min_wall_thickness`
- [ ] M2 pilots use `screw_thread_diameter`; BOM/shopping updated if a new length is needed
- [ ] Clearance for servos, horns, and moving links (fit without sanding)
- [ ] Separate component; features grouped on the timeline
- [ ] Timeline: components → joints (including under `PRINT_LAYOUT`)
- [ ] Servo Configurator: no errors/warnings for any predefined servo
- [ ] Copy (not Paste New) under `PRINT_LAYOUT`, origin joint, print orientation
- [ ] Placed in the correct same-color `PartsSet*` with a joint; bed footprint kept reasonable
- [ ] Parts Exporter export for all servos; `.f3d` + exports committed
- [ ] Docs synced (README parts table / order-parts / assembly as needed)
- [ ] `AiEmblem` not repurposed as branding
- [ ] CERN-OHL-S respected; NOTICE Source Location accurate if distributing Products
- [ ] Optional/mod work under `3d_models/mods/<mod_name>/{cad,parts}/` (+ mod README)

## Related

| Topic | Doc |
| --- | --- |
| Servo params, add-in install, new servo preset | [parametric-design.md](parametric-design.md) |
| Print / part inventory | [`3d_models/README.md`](../../3d_models/README.md) |
| Optional mods folder | [`3d_models/mods/README.md`](../../3d_models/mods/README.md) |
| Order aggregated sets | [order-parts.md](order-parts.md) |
| Mechanical assembly | [assembly.md](assembly.md) |
| Trademark | [TRADEMARK.md](../../TRADEMARK.md) |
| Contribute / licenses | [CONTRIBUTING.md](../../CONTRIBUTING.md) |

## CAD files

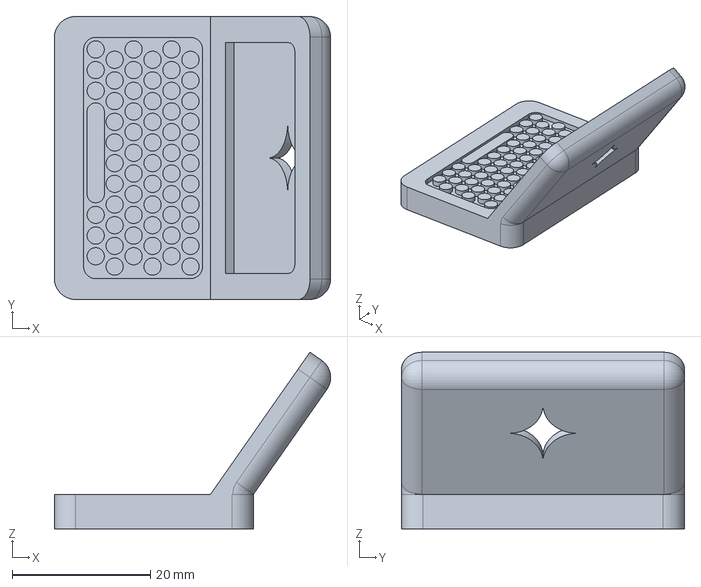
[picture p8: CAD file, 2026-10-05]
3d_models/parts/fs0307/step/LaptopCase.step
40.0 x 41.0 x 25.6 mm

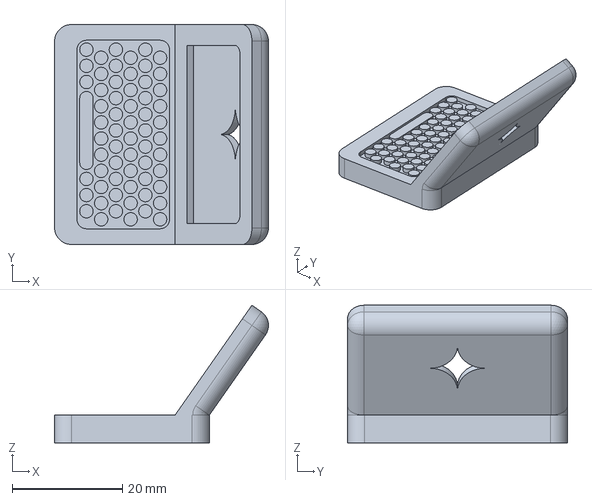
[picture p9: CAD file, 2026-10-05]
3d_models/parts/hd1370a/step/LaptopCase.step
38.8 x 39.9 x 24.9 mm

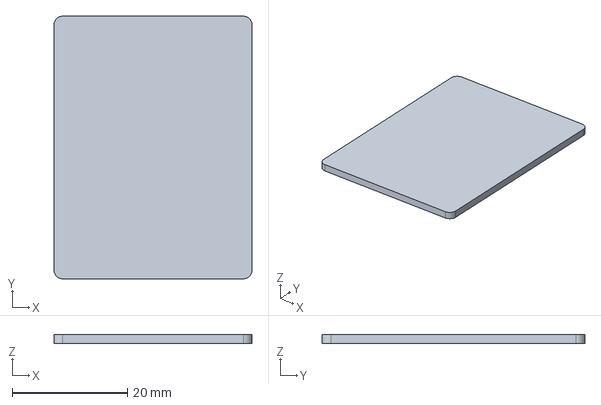
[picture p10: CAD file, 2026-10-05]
3d_models/parts/sg90/step/LaptopScreen.step
34.4 x 45.6 x 1.50 mm

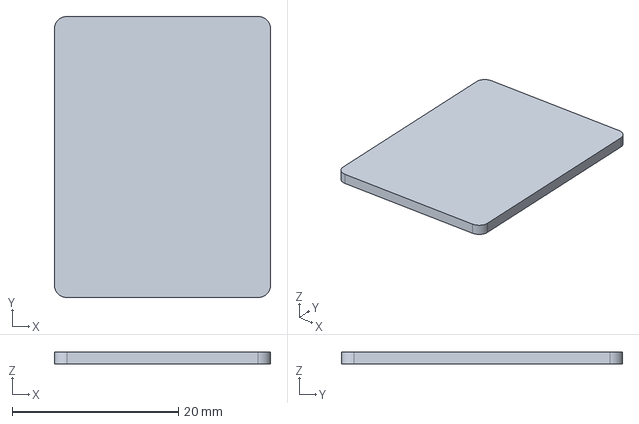
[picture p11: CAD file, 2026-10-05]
3d_models/parts/fs0307/step/LaptopScreen.step
26.0 x 33.8 x 1.50 mm

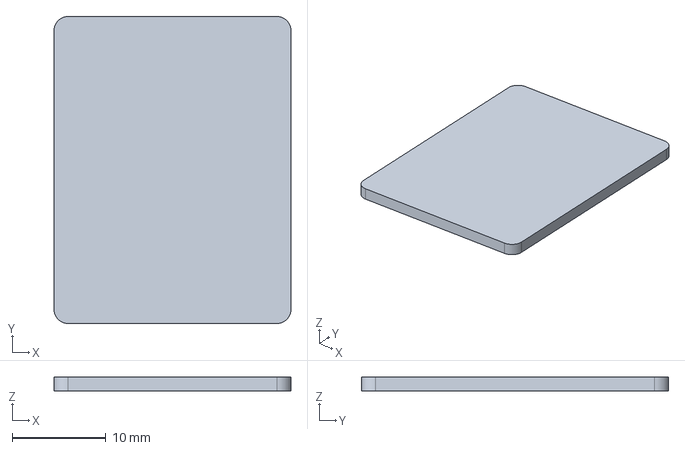
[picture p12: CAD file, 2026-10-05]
3d_models/parts/hd1370a/step/LaptopScreen.step
25.2 x 32.7 x 1.50 mm

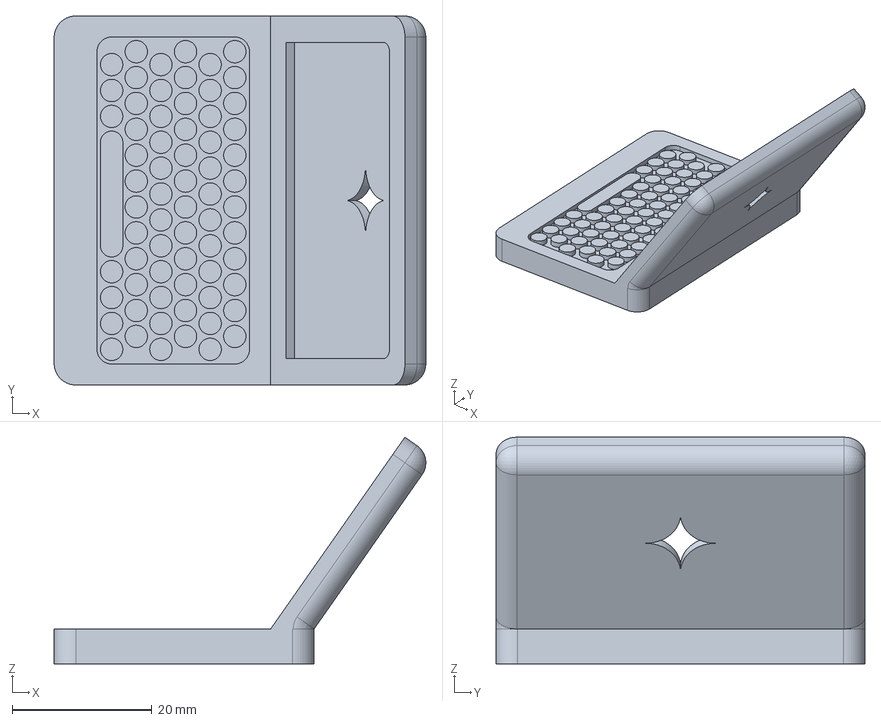
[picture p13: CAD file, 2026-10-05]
3d_models/parts/sg90/step/LaptopCase.step
53.2 x 52.8 x 32.5 mm

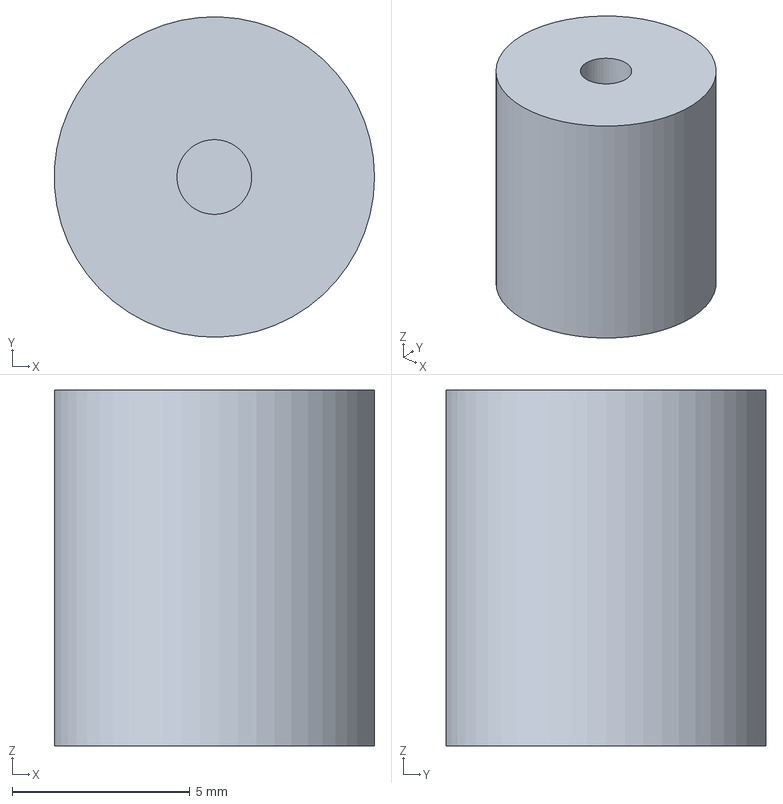
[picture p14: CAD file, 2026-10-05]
3d_models/parts/fs0307/step/Coffee.step
8.99 x 9.00 x 10.0 mm

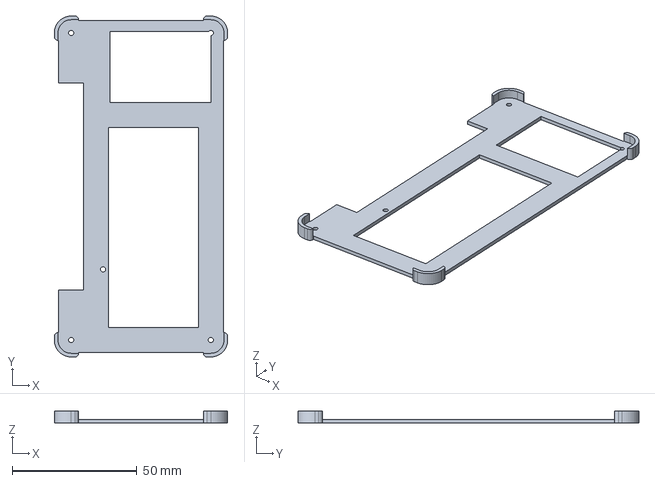
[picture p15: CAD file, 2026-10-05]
3d_models/parts/hd1370a/step/DeskPad.step
69.6 x 136.8 x 5.00 mm

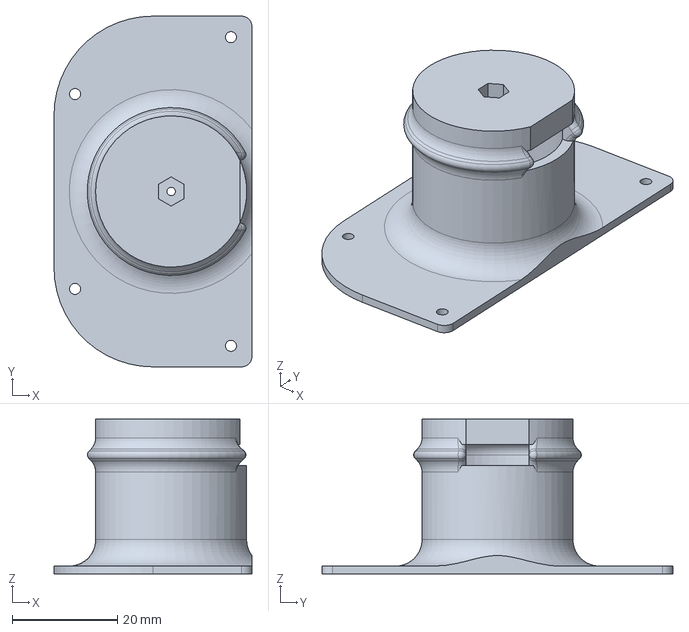
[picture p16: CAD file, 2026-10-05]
3d_models/parts/sg90/step/Belly.step
37.6 x 66.6 x 29.4 mm

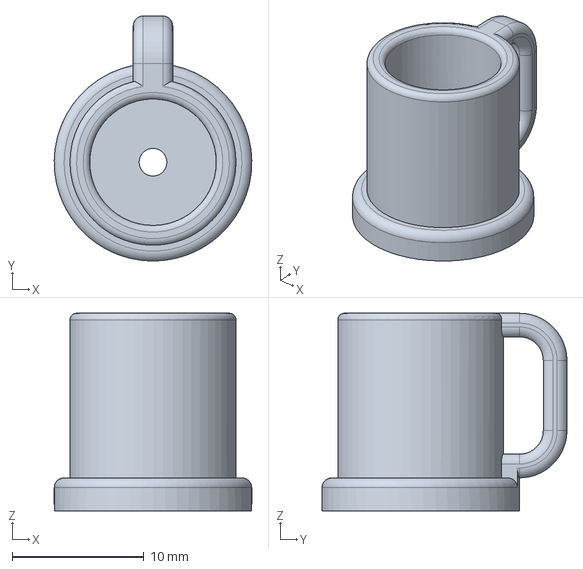
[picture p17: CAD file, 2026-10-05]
3d_models/parts/fs0307/step/Mug.step
15.0 x 18.6 x 15.0 mm

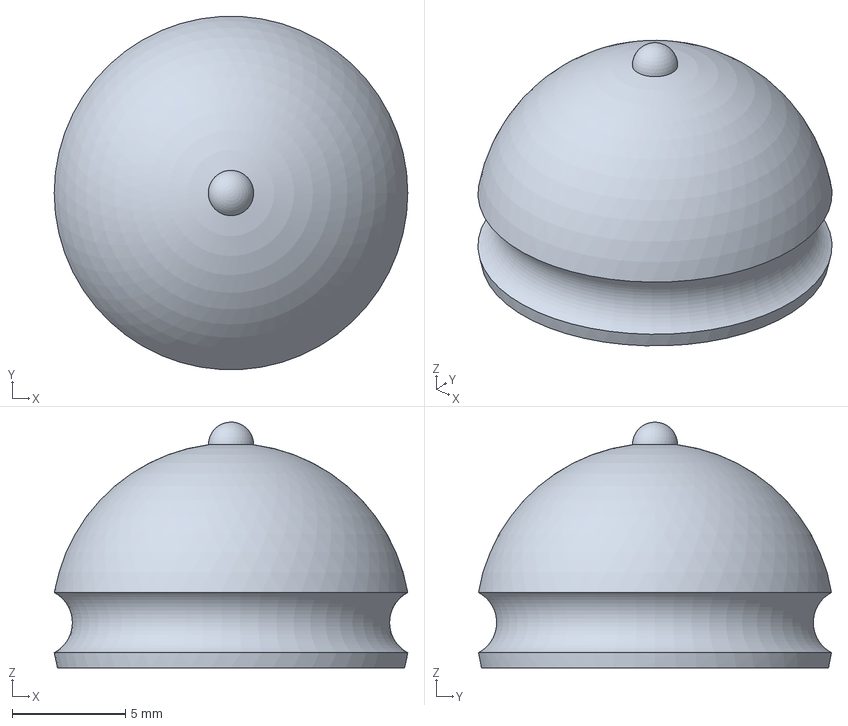
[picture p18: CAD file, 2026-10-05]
3d_models/parts/hd1370a/step/LampCap.step
15.6 x 15.6 x 10.9 mm

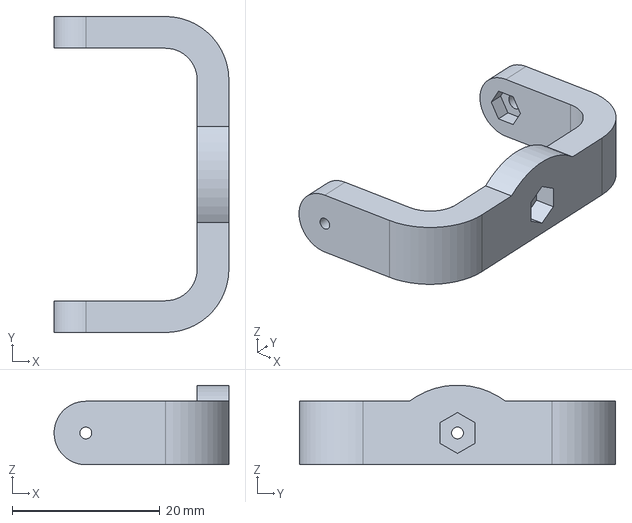
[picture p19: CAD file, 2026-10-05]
3d_models/parts/sg90/step/Neck.step
23.7 x 42.8 x 10.8 mm

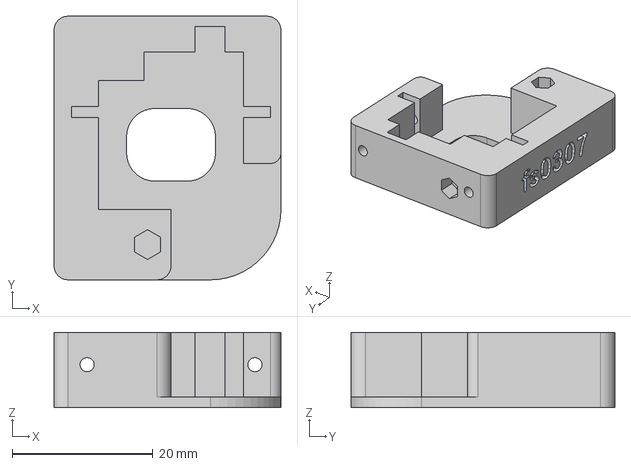
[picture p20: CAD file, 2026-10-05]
3d_models/parts/fs0307/step/ServoSizingTester.step
32.2 x 37.4 x 10.7 mm

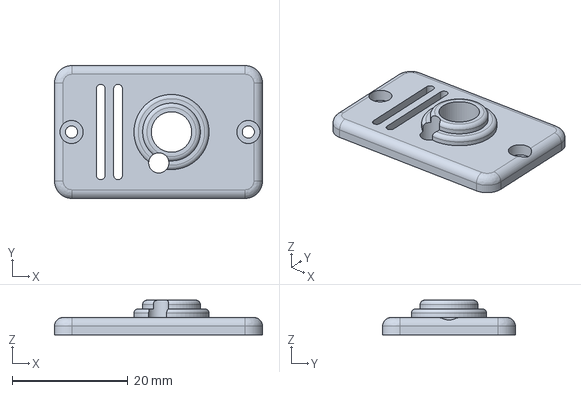
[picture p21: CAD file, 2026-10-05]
3d_models/parts/hd1370a/step/LampBase.step
36.0 x 23.0 x 6.00 mm

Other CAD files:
3d_models/parts/sg90/step/SeatRight.step
3d_models/parts/sg90/step/BottomCover.step
3d_models/parts/fs0307/step/AiEmblem.step
3d_models/parts/hd1370a/step/SeatRight.step
3d_models/cad/TinyEngineer.f3d
3d_models/parts/fs0307/3mf/AiEmblem.3mf
3d_models/parts/fs0307/3mf/Bell.3mf
3d_models/parts/fs0307/3mf/Belly.3mf
3d_models/parts/fs0307/3mf/BottomCover.3mf
3d_models/parts/fs0307/3mf/Chair.3mf
3d_models/parts/fs0307/3mf/Chest.3mf
3d_models/parts/fs0307/3mf/Coffee.3mf
3d_models/parts/fs0307/3mf/Desk.3mf
3d_models/parts/fs0307/3mf/DeskPad.3mf
3d_models/parts/fs0307/3mf/DeskTop.3mf
3d_models/parts/fs0307/3mf/ForearmLeft.3mf
3d_models/parts/fs0307/3mf/ForearmRight.3mf
3d_models/parts/fs0307/3mf/Hat.3mf
3d_models/parts/fs0307/3mf/Head.3mf
3d_models/parts/fs0307/3mf/LampBase.3mf
3d_models/parts/fs0307/3mf/LampButton.3mf
3d_models/parts/fs0307/3mf/LampCap.3mf
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

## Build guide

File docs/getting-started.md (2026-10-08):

# Getting started

Canonical build checklist for Tiny Engineer. Each step: open the linked doc, finish the exit criterion, return here. Mechanical joins live in [assembly.md](3d/assembly.md); this page owns overall order.

Robot already on Wi-Fi? Jump to [step 8](#8-agent-hooks).

## Safety

Read this before you power anything. Optional primer, not a gate: [From Code to Circuits](hardware-for-software-engineers/README.md).

- Supply **5 V / ≥2 A** on the board USB-C.
- Speaker: connector **or** solder pads, never both. **SPK− is not ground.**
- Leave the C3-Zero ceramic antenna clear of metal and dense plastic.

## Timeline

Shop → print → connect → flash → assemble (one run) → setup wizard → prove → agent hooks.

The default build uses the **main control board**. Plug in the ESP32, OLED, servos, and speaker. To add modules the board does not carry, follow the harness rules in [wiring.md](hardware/wiring.md) and mount them with [assembly-modular.md](3d/assembly-modular.md).

```mermaid
flowchart LR
  shop[Shop]
  print[Print]
  connect[Connect]
  flash[Flash]
  mech[Assemble]
  wiz[Wizard]
  prove[Prove]
  agent[Agent]

  shop --> print --> connect --> flash --> mech --> wiz --> prove --> agent
```

## Checklist

### 1. Shop

- **Open:** [shopping.md](shopping.md). Default cart is the main control board plus the ESP32, OLED, servos, and speaker.
- **Until:** cart in hand — main control board, ESP32, servos, OLED, speaker, M2 screws/nuts, **5 V / ≥2 A** supply, **data** USB cable, and a print path (filament or a service order). Default servos: **Tower Pro SG90**.
- **Return** here.

### 2. Print or order

- **Open:** [3d_models/README.md](../3d_models/README.md) (home print; testers first) or [3d/order-parts.md](3d/order-parts.md) (no printer).
- **Until:** printed set for your servo model ready.
- **Return** here.

### 3. Connect

- **Open:** [hardware/main-control-board.md](hardware/main-control-board.md).
- **Until:** pre-power checks pass (speaker on **SPK+/SPK−** only, one method; servo plugs match the labels; ESP32 orientation matches the PCB USB mark). Electronics stay on the desk.
- **Advanced:** extra modules the board does not support — wire the harness now ([hardware/wiring.md](hardware/wiring.md)). Mount those boards during assembly ([3d/assembly-modular.md](3d/assembly-modular.md)).
- **Return** here.

### 4. Flash

- **Open:** **[Web flash](https://jamro.github.io/tiny-engineer/flash/)** (Chrome or Edge; USB-C **data** cable). Pick the latest release → Connect & install. No PlatformIO or repo clone needed for stock firmware. More detail / stuck / advanced: [flash.md](flash.md).
- **Until:** stock firmware + audio on the board; **Move all to 90°** (setup AP config page) or one servo moves. Do not finish the Wi-Fi wizard yet.
- **Return** here. Keep electronics on the desk — do not seat them in the chest yet.

### 5. Assemble

- **Open:** [3d/assembly.md](3d/assembly.md) from §1 through §19 (Head/Hat, centering, joins, channels, arms, lamp).
- **Until:** all joins done; servo and OLED headers plugged per the guide.
- **Return** here.

### 6. Setup wizard

- **Open:** [3d/assembly.md §20](3d/assembly.md#20-setup-wizard-and-first-boot-on-wi-fi).
- **Until:** wizard finished, power-cycled, robot on home **2.4 GHz** Wi-Fi.
- **Return** here.

### 7. Prove it

Open `http://tiny-engineer.local/` (or the IP on the OLED) for the web UI.

```bash
curl http://tiny-engineer.local/health
curl -X POST "http://tiny-engineer.local/anim?name=ring"
```

- **Until:** `/health` OK and `ring` runs (motion; sound if LittleFS uploaded). If `.local` is slow, use the OLED IP or `curl -4`.
- **Return** here. Full API: [api.md](api.md).

### 8. Agent hooks

- **Open:** [integration.md](integration.md) — `tiny-engineer setup` (default) or REST for custom agents. Cursor details: [hooks.md](hooks.md).
- **Until:** optional — an agent event triggers an animation.
- Done.

## Stuck?

| Symptom | What to try |
| --- | --- |
| Extra modules the board does not support? | [shopping.md](shopping.md#advanced-extra-modules) · [hardware/wiring.md](hardware/wiring.md) |
| What to buy? | [shopping.md](shopping.md) |
| How to plug in the board? | [hardware/main-control-board.md](hardware/main-control-board.md) |
| What to print? | [3d_models/README.md](../3d_models/README.md) |
| How to assemble printed parts? | [3d/assembly.md](3d/assembly.md) |
| Flash / install stuck | [Web flash](https://jamro.github.io/tiny-engineer/flash/) · [flash.md](flash.md) |
| `.local` slow or fails | OLED IP; `curl -4 http://…` |
| OLED shows join AP / `192.168.4.1` | Wi-Fi not saved or STA failed — finish [assembly §20](3d/assembly.md#20-setup-wizard-and-first-boot-on-wi-fi) |
| Welcome / ring silent (servos move) | Re-install the same release from [Web flash](https://jamro.github.io/tiny-engineer/flash/) (stock image includes audio). Advanced: [flash.md](flash.md) |
| Hooks never move the robot | Node 18+, `npx -y tiny-engineer doctor`, hook `timeout` ≥ 30 for cold `npx` — see [integration.md](integration.md) / [hooks.md](hooks.md) |
| Servos twitch / board resets on motion | Power budget — [hardware/power.md](hardware/power.md) |
| Other boot / I2C / audio failures | [hardware/testing.md](hardware/testing.md) |

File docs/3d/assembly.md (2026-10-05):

# Mechanical assembly

How to join the printed parts and seat the five micro servos. Use **M2 screws** that thread into the plastic — no glue, no heat-set inserts.

Follow [getting-started.md](../getting-started.md) for overall build order; this file is the mechanical procedure. Start here **after** connecting and flashing.

Screw lengths called out below (M2×4 / ×8 / ×16) match the reference list. If you substitute nearby lengths, **test-fit** first. Totals: [3d_models/README.md → Screws](../../3d_models/README.md#screws). Buyer cart: [shopping.md](../shopping.md).

**Before you start:** the main control board is connected on the desk and firmware is flashed ([main-control-board.md](../hardware/main-control-board.md), then [flash.md](../flash.md)). Print or order the set for your servo model ([3d_models/README.md](../../3d_models/README.md), [order-parts.md](order-parts.md)). All five servos are the same type; the printed pockets match that model. Breakout modules: [assembly-modular.md](assembly-modular.md) replaces §12 and §13 below.

**Left / right:** throughout this guide, “robot’s left” and “robot’s right” mean the **figure’s** sides — not your left/right as you face it.

### Build map

1. Head + Hat (OLED + head servo)
2. Center Neck → join Head/Neck → Chest side servos → mount on Chest → Belly → Chair
3. Desk stack → mount electronics → plug channels → Chair↔Desk → BottomCover
4. Arms → Lamp → setup wizard

## 1. Head — OLED and servo

1. Peel the protective sticker off the Waveshare OLED screen.
2. Plug the cable that shipped with the Waveshare OLED into the display **before** seating it. Once the OLED is in its pocket, the connector is hard to reach.
3. Take one of the five identical micro servos. Do **not** attach a horn yet. Orientation does not matter at this stage.
4. Seat the servo and the OLED into their dedicated pockets in the printed `Head`.
5. Route both cables through the openings in the shell — OLED cable on one side of the head, servo lead on the opposite side.
6. Clip each cable into the molded cable clips on the **back** of `Head` (clips are part of the print).

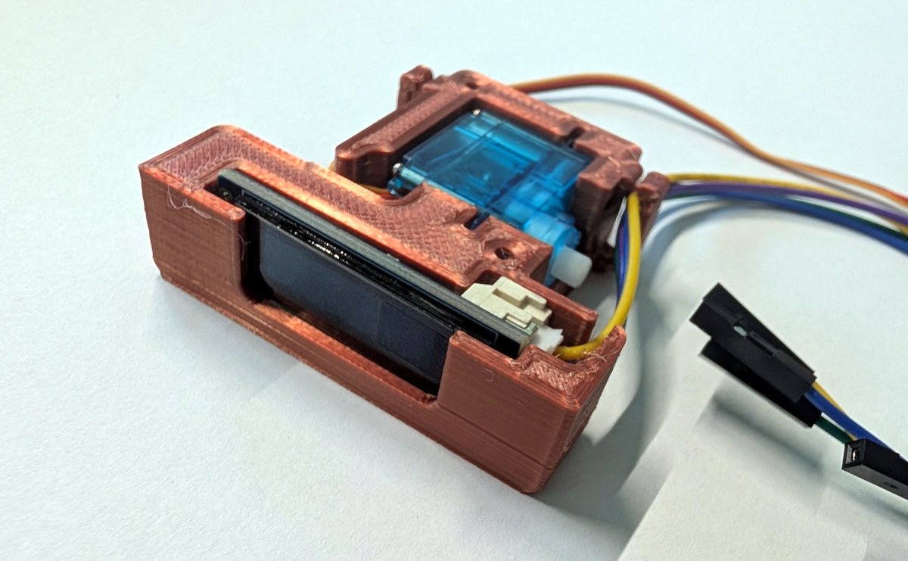
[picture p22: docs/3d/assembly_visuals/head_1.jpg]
Head


## 2. Hat

1. Place `Hat` on top of `Head`.
2. Fasten with **two M2 screws** (M2×8 mm works). Thread into the printed plastic — do not overtighten.

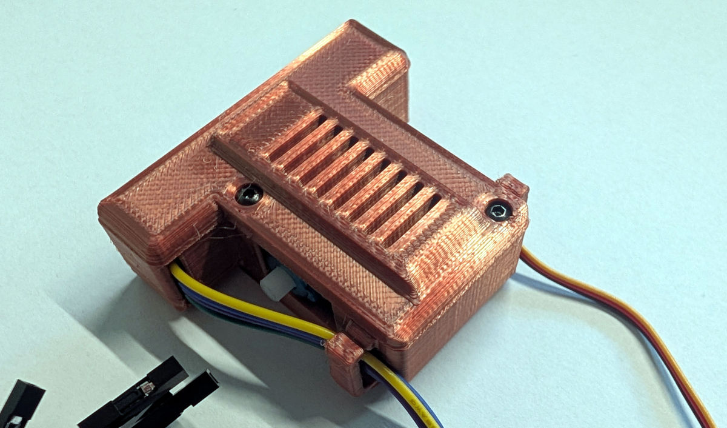
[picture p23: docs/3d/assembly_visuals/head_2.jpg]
Head


## 2a. Bench window (centering)

Electronics and firmware should already be done ([getting-started](../getting-started.md) connect + flash). If the module is not flashed yet, stop and do [flash.md](../flash.md) first. From here on you set each printed part on a servo that is already at **90°** (shaft center).

**Bench window:** keep the electronics on the desk — do **not** seat them in the chest until [§12](#12-electronics-inside-the-desk).

> **Stop.** Join the setup AP only to press **Move all to 90°**. Do **not** finish the wizard (ranges, OLED, LED, speaker, home Wi-Fi) until [§20](#20-setup-wizard-and-first-boot-on-wi-fi).

After each centering step, **unplug the servo from the PCA9685** before you keep building. Leaving the lead attached makes the next joins awkward. You reconnect the correct channels later.

### Center a servo

Use this recipe whenever a later step says to center a servo:

1. Plug the servo into any PCA9685 channel (channel mapping does not matter for centering).
2. Power the ESP32. Join the setup Wi‑Fi (`TinyEngineer-XXXX`), open `http://192.168.4.1/config`, and press **Move all to 90°**. The shaft is now at electrical center.
3. After you finish that joint, **unplug** the servo from the PCA9685 before the next awkward join.

## 3. Neck — center a servo and attach `Neck`

1. Take the **next** unused servo (not the one already in `Head`). Do **not** attach a plastic horn — `Neck` mounts on the shaft.
2. [Center that servo](#center-a-servo).
3. Press `Neck` onto the servo shaft so the part sits **perpendicular** to the servo body.
4. Align the raised bulge in the middle of `Neck` toward the **back** of the servo — the longer end of the servo body (cable / electronics side).
5. Fasten `Neck` with the **screw that came with the servo**, keeping that perpendicular orientation.
6. Drop an **M2 nut** into a hexagonal pocket on `Neck`:
   - Use the pocket with the **larger** center hole.
   - That pocket is on the **robot’s right**.
   - The pocket with the smaller hole is for mounting a servo later — leave it empty for now.
7. Unplug this servo from the PCA9685 so the next steps are easier to handle.

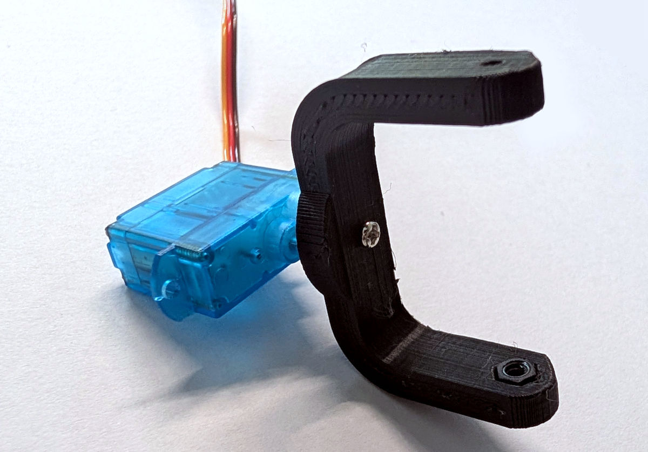
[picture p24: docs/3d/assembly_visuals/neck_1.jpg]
Neck


## 4. Join `Neck` and `Head`

1. [Center](#center-a-servo) the servo already inside `Head`.
2. Take the `Neck` assembly from §3. **First stage:** fit `Neck` onto the Head servo shaft — `Neck` has a dedicated pocket for that shaft. Gently push the Head cables aside if needed so the shaft seats fully.
3. **Second stage:** slide `Neck` further onto `Head` until the side with the M2 nut sits flush with `Head` and lines up with the mounting hole on that side. Keep the nut in its hex pocket so it does not fall out.
4. At 90°, `Neck` must sit **perpendicular** to `Head`. Adjust before fastening if needed.
5. Fasten `Neck` to `Head`:
   - Robot’s right: M2 screw into the captured nut (M2×8 mm works).
   - Robot’s left: the mounting screw that came with the servo.
6. Unplug the Head servo from the PCA9685 before continuing.

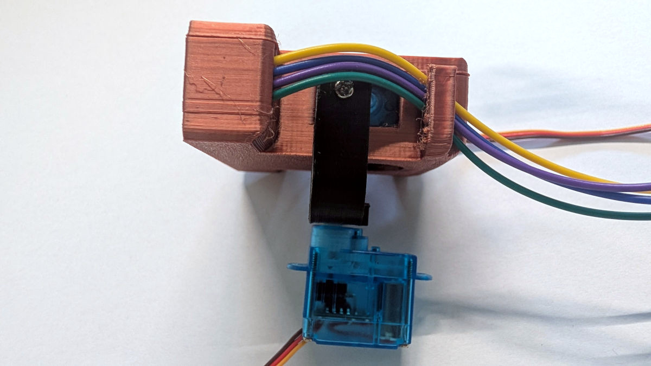
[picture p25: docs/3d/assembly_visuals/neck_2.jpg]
Neck


## 5. Chest — side servos

1. Take the printed `Chest`.
2. Seat **two** unused servos in the side pockets (left and right). No horns yet. Shaft orientation does not matter — you will calibrate later.
3. Route each servo lead through the **vertical tunnel at the front** of `Chest` so the connectors exit from the **bottom** of the part.
4. Fasten both servos with **four M2 screws** total — two per servo (M2×16 mm works). Do not overtighten.

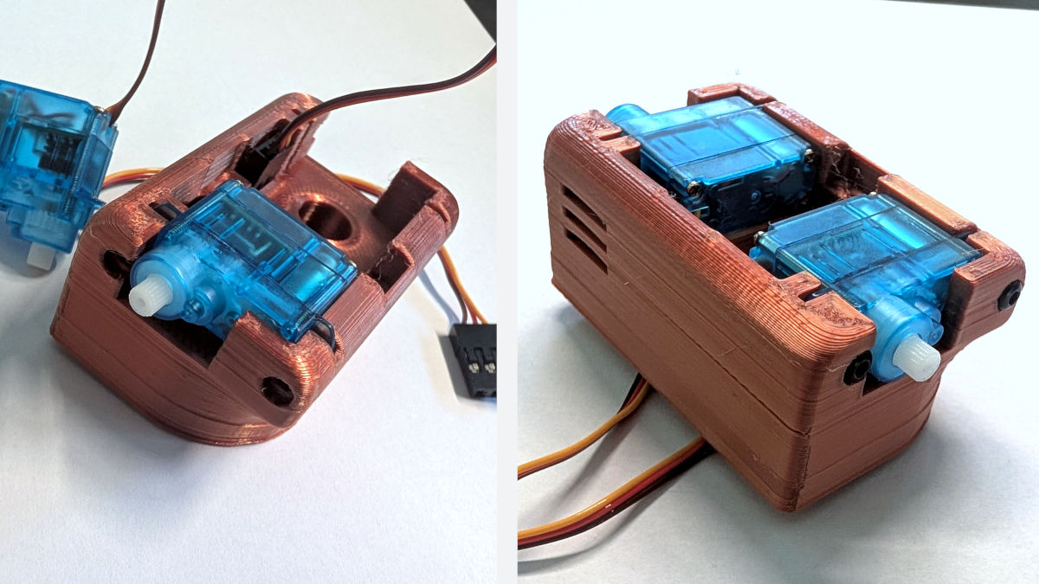
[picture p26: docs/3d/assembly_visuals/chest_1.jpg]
Chest


## 6. Mount head assembly on `Chest`

1. Take the joined `Head` + `Neck` from [§4](#4-join-neck-and-head). The servo already fastened to `Neck` goes into the **center** servo pocket in `Chest`.
2. **Before** seating that servo, route its lead through the **central tunnel** in `Chest` and out the **bottom** of the part.
3. Seat the Neck servo fully in the center pocket. Keep front of `Head`/`Neck` on the same side as front of `Chest` (the side with the cable tunnels).
4. Fasten it to `Chest` with M2×8 mm screws. Prefer two screws; if space is tight, one screw at the back of the robot is enough.

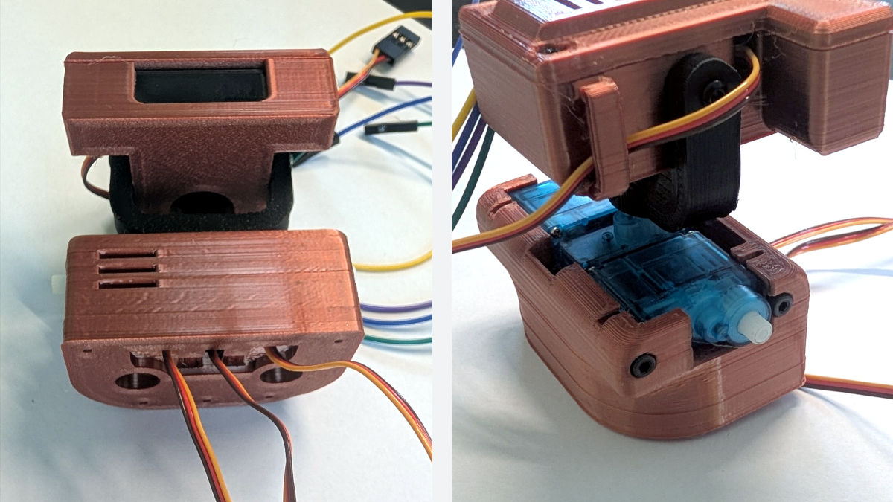
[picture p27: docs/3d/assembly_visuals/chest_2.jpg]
Chest


## 7. Belly — last servo

1. Take the **last** unused servo. [Center it](#center-a-servo).
2. Press `Belly` onto the servo shaft — `Belly` has a dedicated pocket for the shaft. Do **not** use a plastic horn.
3. Orient the servo **perpendicular** to `Belly`, with the longer end of the servo body toward the **rounded** side of `Belly`.
4. When alignment is correct, fasten with the **screw that came with the servo**.
5. Unplug this servo from the PCA9685 before continuing.

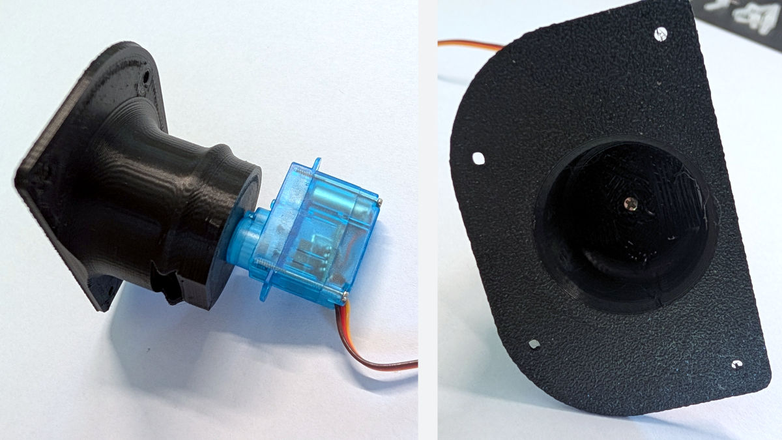
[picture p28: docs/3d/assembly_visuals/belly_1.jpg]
Belly


## 8. Route chest cables through `Belly` and join

1. Take the three servo leads that exit the bottom of `Chest`: Neck (center) and the two side (hand) servos.
2. Pass them into `Belly` through the **large upper** opening, then out through the **lower side** opening.
3. Keep the same left-to-right order as they leave `Chest`: **left hand → neck → right hand**. That order is only an identification aid for later — not the PCA9685 channel sequence.
4. Orient `Belly` so its rounded side faces the **back** and matches the profile of `Chest`, then fasten with **four M2 screws** (M2×8 mm works).

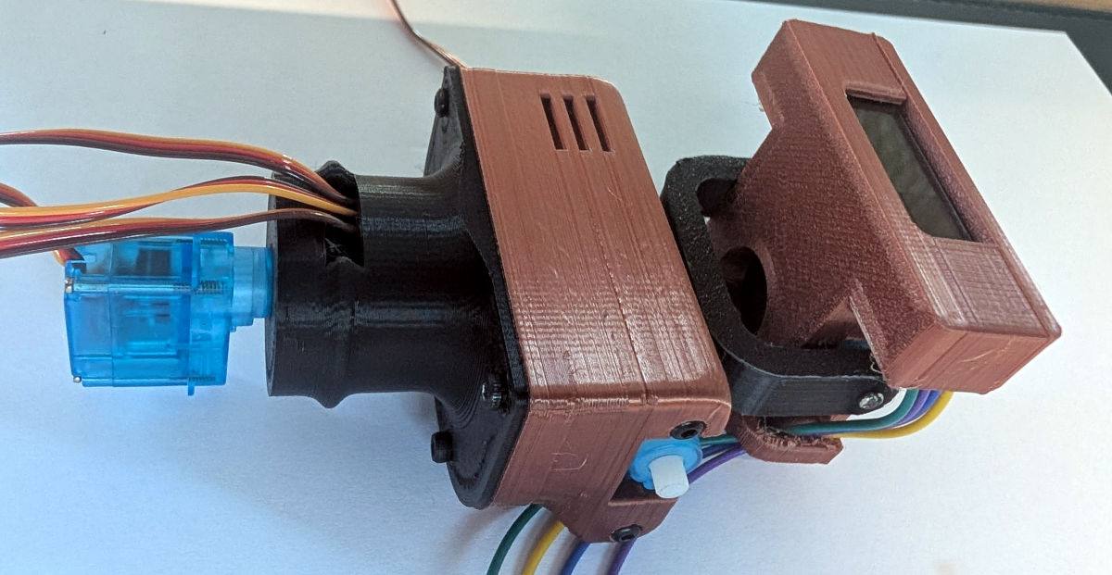
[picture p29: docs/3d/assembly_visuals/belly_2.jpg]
Belly


## 9. Seat the body in `Chair`

1. Take the robot body (`Head` through `Belly`). The servo already fastened to `Belly` goes into the dedicated pocket in `Chair`.
2. Orient so the front of the robot matches the front of the chair (the way the figure sits).
3. Route that servo’s lead through the **vertical tunnel** in `Chair` and out under the chair.
4. Slide `SeatLeft` and `SeatRight` in from the sides onto the rails / pockets on `Chair`. The seats lock the body servo in place so it cannot drop out of `Chair`. Watch the cables — do not pinch or crush them while seating the parts.
5. Fasten the two seat parts to each other with **two M2 screws** (M2×16 mm works).

This finishes the **main robot body**. Set it aside — next steps build the desk.

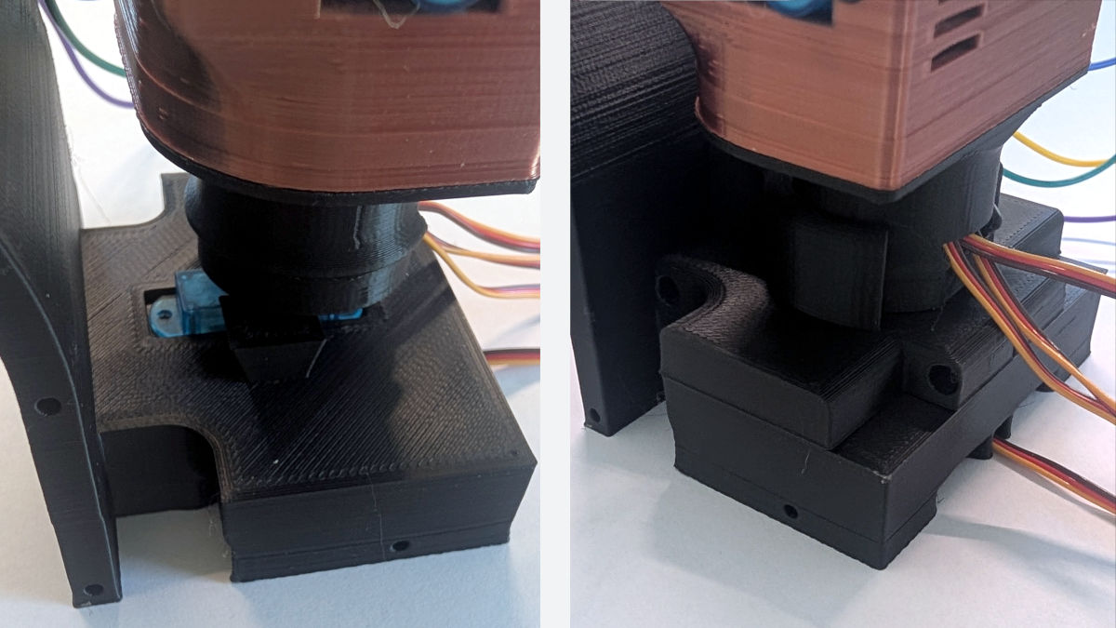
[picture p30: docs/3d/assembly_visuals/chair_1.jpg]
Chair


## 10. Desk top stack

1. Take `DeskTop`, `DeskPad`, and `Desk`.
2. Seat `DeskTop` into `DeskPad` — the parts nest together.
3. Place that stack onto `Desk`. Orient so the rounded cutout faces the robot (the side where the figure sits).
4. Fasten through the four corner holes with **four M2 screws** (M2×16 mm works).

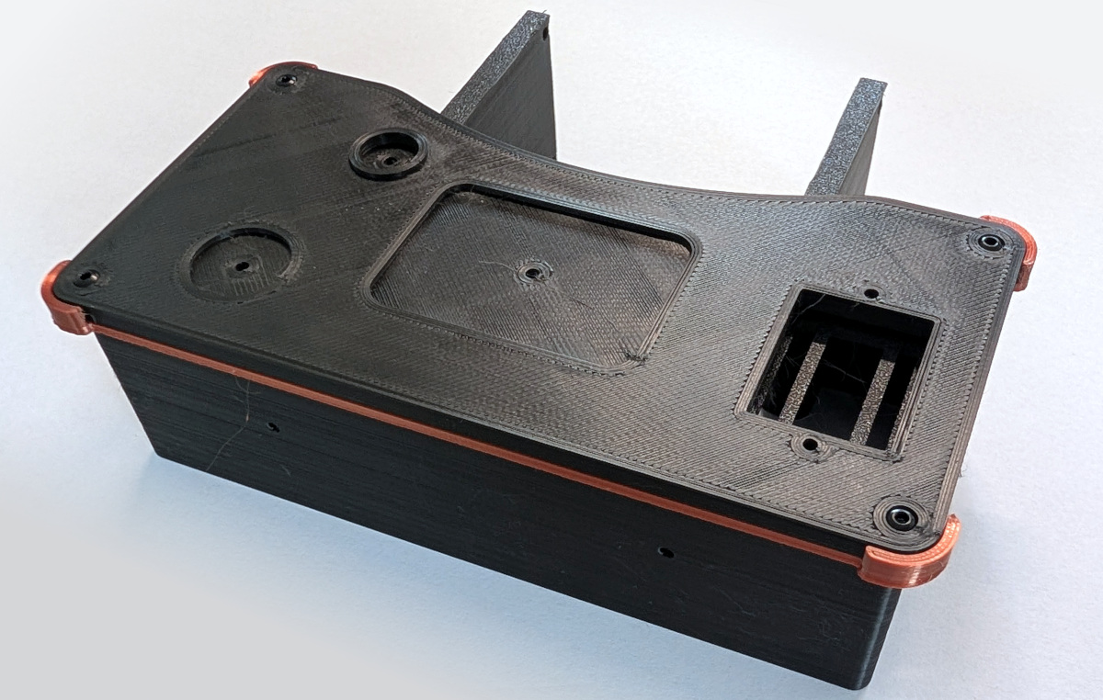
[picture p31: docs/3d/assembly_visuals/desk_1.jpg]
Desk


## 11. Desk emblem

1. Place `AiEmblem` on the front of the desk.
2. Fasten with **two short M2 screws** (M2×4 mm works).

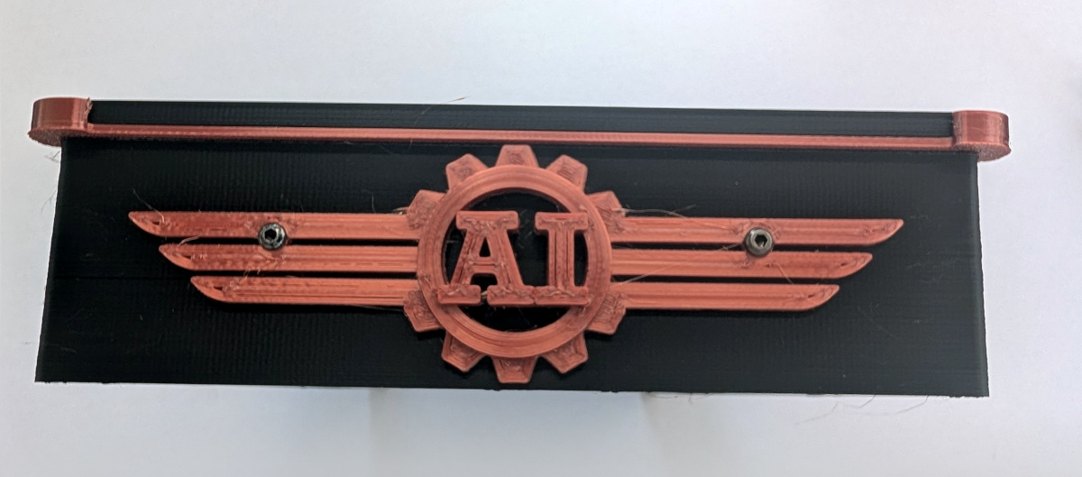
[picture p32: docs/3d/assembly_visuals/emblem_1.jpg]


## 12. Electronics inside the desk

Seat the **main control board** in `Desk`. This step mounts what you already connected on the desk ([getting-started](../getting-started.md) connect + flash). Electrical plugs: [main-control-board.md](../hardware/main-control-board.md). Breakout modules: [assembly-modular.md](assembly-modular.md).

1. Seat the board in the desk cavity.
2. Leave servos and the OLED unplugged until [§15](#15-connect-servos-and-oled).
3. **Speaker** — finish the board connector or the solder pads per the connect guide (one method only). Stick or tuck the speaker inside the desk as needed.
4. Leave the ESP32 out until [§13](#13-esp32-powerap-smoke-test-and-lampbase) — it seats from above into the board headers through the desk-top cut.

## 13. ESP32, power/AP smoke test, and `LampBase`

1. Seat the **ESP32-C3-Zero** in the desk-top opening from above so its pins pass through the cut **into the board headers** underneath. Orient using the **USB** marking on the PCB ([main-control-board.md](../hardware/main-control-board.md)). The module should sit flush and not stick up above the desk surface.
2. **Power/AP smoke test** (optional but recommended) before locking the module in:
   - Confirm seating and orientation. Servo plugs and the OLED come in [§15](#15-connect-servos-and-oled).
   - Firmware should already be on the module.
   - Apply power on the **board USB-C**. The ESP32 LED should light and the board should start the **setup access point**.
   - If that looks good, **disconnect power**.
3. Place the printed `LampButton` under `LampBase` so it can press the ESP32 **reset** button from above.
4. Orient `LampBase` so its opening sits over the ESP32 status LED.
5. Fasten `LampBase` to the desk with **two M2 screws** (M2×8 mm works). This also holds the ESP32 from above.

## 14. Desk props — laptop, mug, bell

1. **Laptop** — slide `LaptopScreen` into the pocket on the underside of `LaptopCase`. Place the laptop on the desk and fasten with one M2 screw from under the desk (M2×8 mm works).
2. **Mug** — seat `Coffee` inside `Mug`. Place the mug in its dedicated spot on the desk and fasten the same way: one M2 screw from under the desk (M2×8 mm works).
3. **Bell** — first drive the M2 screw fully into `Bell` alone (M2×16 mm works). Then, with the screw already in the bell, drive that screw down into the desk from above and secure with an M2 nut underneath.

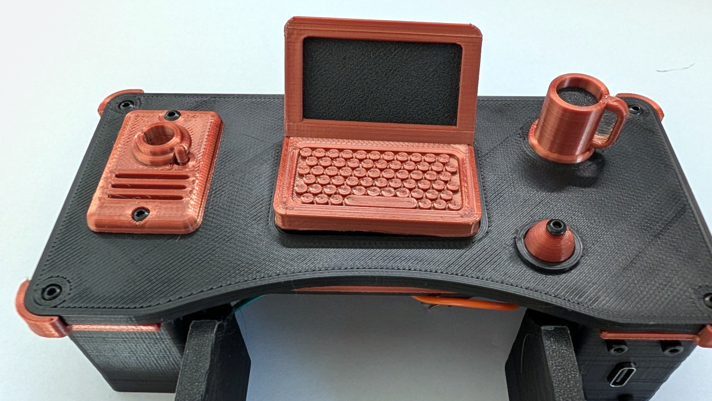
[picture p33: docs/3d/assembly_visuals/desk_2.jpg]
Desk


## 15. Connect servos and OLED

Easiest with the desk tipped onto its front wall so the servo headers face up, and the seated robot body beside it.

1. Plug every servo lead and the OLED cable into the labeled board headers ([main-control-board.md](../hardware/main-control-board.md)). Breakout build: plug them into the PCA9685 and the harness — [assembly-modular.md](assembly-modular.md).
2. Use the correct PCA9685 channel order following labels on the board ([pinout](../hardware/pinout.md#pca9685-channels-not-esp32-gpio)):

   | Channel | Joint |
   | --- | --- |
   | 0 | Head pitch |
   | 1 | Neck yaw |
   | 2 | Left hand |
   | 3 | Right hand |
   | 4 | Body / torso |

3. Power up and run a **servos + OLED smoke test**: servos respond, OLED shows something sensible, no brown-out or odd movement. If something is wrong, power down before swapping plugs.

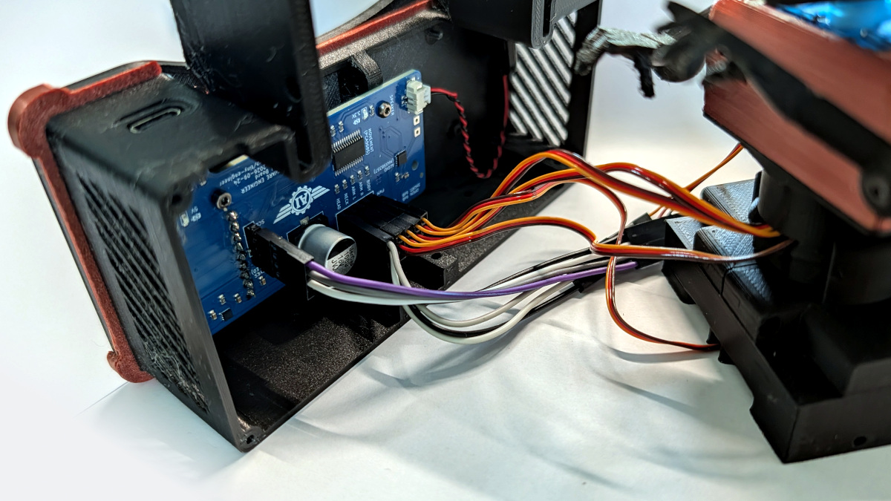
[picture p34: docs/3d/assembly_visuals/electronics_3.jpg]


## 16. Fasten `Chair` to `Desk`

1. Gently slide the desk up to the chair so the mounting holes on the desk (back / armrest sides) line up with the matching holes on `Chair`.
2. Fasten with **six M2 screws** total — three per side (M2×8 mm works). Do not force the parts; keep cables clear of the screw paths.

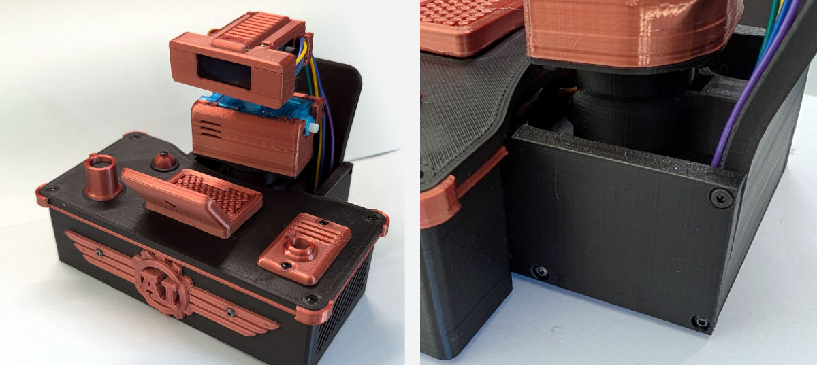
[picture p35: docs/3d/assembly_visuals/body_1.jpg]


### Close the underside with `BottomCover`

1. Finish the servo and OLED cables and the six side screws joining `Chair` to `Desk` first. Power down, support the robot, and turn it over without loading the arms or desk props.
2. Route the chair leads through the existing tunnel and into the desk cavity. Keep the cables inside the perimeter, away from all six cover screw paths; no wire should sit between the cover and the chair/desk mating surfaces.
3. Use the updated `Chair` from the same servo folder: it has two reinforced blind pilot holes underneath its rear wall. An older chair without these holes must be reprinted for the six-point attachment; keep clear of the existing side screws and cables.
4. Place the flat mating face of `BottomCover` against the desk and chair. Its stem follows the chair; the recessed pockets face outward. Align the four desk holes and the two rear chair holes.
5. Fasten with **six M2×8 mm** pan/button-head screws — four into the desk and two into the chair. Heads no larger than **4.0 mm diameter × 2.0 mm high**. No nuts.
6. Tighten until each head sits in its pocket and none sticks past the flat underside. No trapped wires. Set the robot upright.

Print `BottomCover` with its **mating face down and pockets up**, as exported. No supports. Printed fit still needs a test-fit.

## 17. Arms — elbow joints

Build the arm assemblies only — do **not** mount them on the chest servos yet.

1. At each elbow there is a screw hole joining the forearm to the upper arm.
2. Fasten left and right the same way: `ForearmLeft` to `UpperArm` and `ForearmRight` to `UpperArm` with one M2 screw per elbow (M2×8 mm works). Print / use two `UpperArm` parts (one per side).

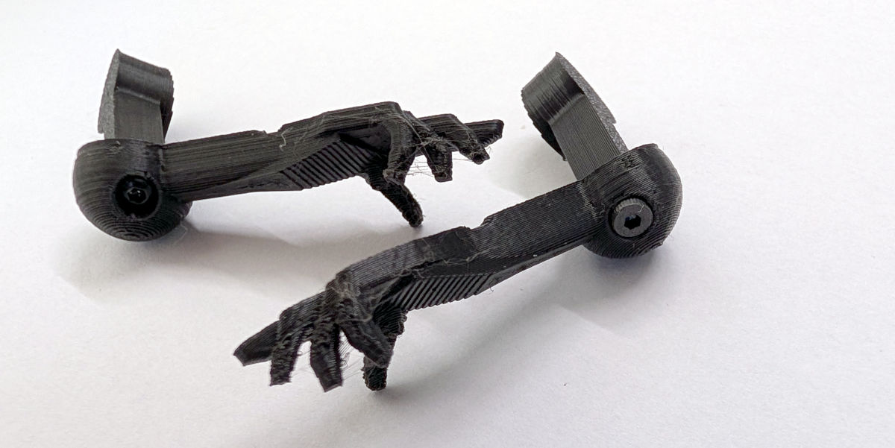
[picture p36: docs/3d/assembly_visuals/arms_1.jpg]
Arms


## 18. Mount arms on the chest servos

1. [Center](#center-a-servo) the side (hand) servos first.
2. Press each arm assembly onto its chest servo shaft. The upper arms have dedicated pockets for the shafts.
3. With the servos at 90°, set each arm so the hand sits at about shoulder height and the forearm points forward (toward the desk).
4. When the pose looks right, fasten each arm with the mounting screw that came with that servo.
5. Do this for both arms. If centering is not perfect, that is fine — you will refine it in the setup calibration later.

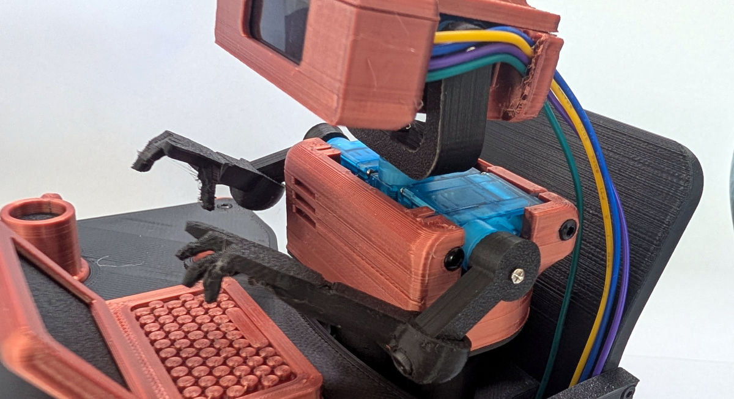
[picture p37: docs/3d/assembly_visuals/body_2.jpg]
Body


## 19. Lamp (press-fit)

No screws — everything is a friction fit.

1. Place `LampCap` onto `LampDiffuser`.
2. Push that stack into the opening in `LampBase`.

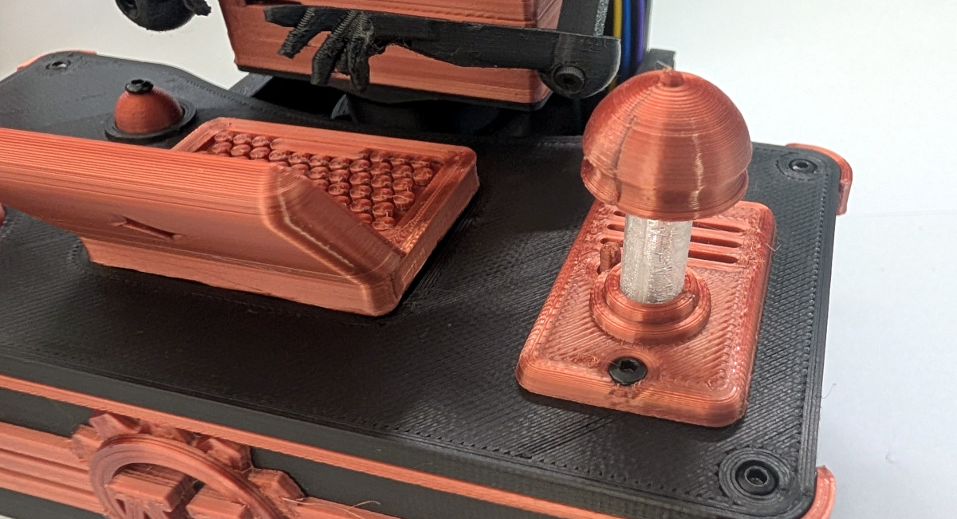
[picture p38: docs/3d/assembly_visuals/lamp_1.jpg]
Lamp


## 20. Setup wizard and first boot on Wi-Fi

The robot is built. What remains is servo calibration, Wi-Fi, and a quick check that everything works.

1. Connect power. The board should start the **setup access point** (`TinyEngineer-XXXX`). First boot, or after factory reset + power-cycle.
2. Join that Wi-Fi and open the configurator (`http://192.168.4.1/config`).
3. Walk through the **entire setup wizard**:
   1. Seat printed parts on the servo shafts at 90°, then mark each joint’s safe min/max (factory reset keeps prior ranges; you can still change them here).
   2. Look at the OLED and tap Rotate 180° if text is upside down (factory reset keeps the rotation).
   3. Tap Red/Green/Blue on the onboard LED; change mapping only if colors look wrong (default **GRB**; factory reset keeps the mapping).
   4. Play the welcome clip through the speaker.
   5. Hostname and home Wi-Fi (**2.4 GHz** only). OLED shows join-AP steps.
4. When the wizard is finished, **disconnect power**, then power on again.
5. The robot should join your home network and expose the **REST API**. Prove it — [getting-started §7](../getting-started.md#7-prove-it), [api.md](../api.md).

Wi-Fi is not editable from the normal Config page later — factory reset to change it.

## Related

| Topic | Doc |
| --- | --- |
| Overall build checklist | [getting-started.md](../getting-started.md) (assemble is [§5](../getting-started.md#5-assemble)) |
| Shopping list | [shopping.md](../shopping.md) |
| Parts inventory / printables | [3d_models/README.md](../../3d_models/README.md) |
| Print or order parts | [getting-started §2](../getting-started.md#2-print-or-order) · [order-parts.md](order-parts.md) |
| Different servo size / CAD params | [parametric-design.md](parametric-design.md) |
| Servo axes and safe ranges | [robot-movement.md](../robot-movement.md) |
| Connect and flash (before this page) | [hardware/main-control-board.md](../hardware/main-control-board.md) · [flash.md](../flash.md) |
| Extra modules (advanced) | [assembly-modular.md](assembly-modular.md) · [hardware/wiring.md](../hardware/wiring.md) |

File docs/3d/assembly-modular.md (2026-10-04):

# Modular assembly (advanced)

Mount breakout modules in the printed `Desk`. Use this when you add hardware the main control board does not support.

The default build seats the [main control board](../hardware/main-control-board.md) — follow [assembly.md](assembly.md) §12 and §13. This page replaces those two steps only. Electrical harness: [wiring.md](../hardware/wiring.md).

By this point the breakouts should already be wired and soldered as one harness, and firmware flashed ([flash.md](../flash.md)). Then return to [assembly §14](assembly.md#14-desk-props--laptop-mug-bell). Servo channel order is the same table in [assembly §15](assembly.md#15-connect-servos-and-oled); plug the leads into the PCA9685 instead of the board headers.

## Electronics inside the desk

**Leave disconnected for now:**

- ESP32 — attach the gold-pin jumper cables to the ESP32 pins in the next section
- PCA9685 — plug servo connectors in [assembly §15](assembly.md#15-connect-servos-and-oled)

Everything else in the harness stays as already soldered and assembled.

1. **USB-C breakout (Adafruit 5993)** — fasten with four longer M2 screws (M2×16 mm works) and secure with M2 nuts.
2. **PCA9685** — fasten to the rails on the inside of the desk front with four short M2 screws (M2×4 mm works).
3. **MAX98357A** — mount on the single rail on that same inner front wall with two M2 screws (M2×4 mm works).
4. **Speaker** — stick it to an inner wall, or leave it loose inside the desk for now.

Mount in that order — USB first, then PCA9685, then MAX98357A, then the speaker — so later boards are not in the way.

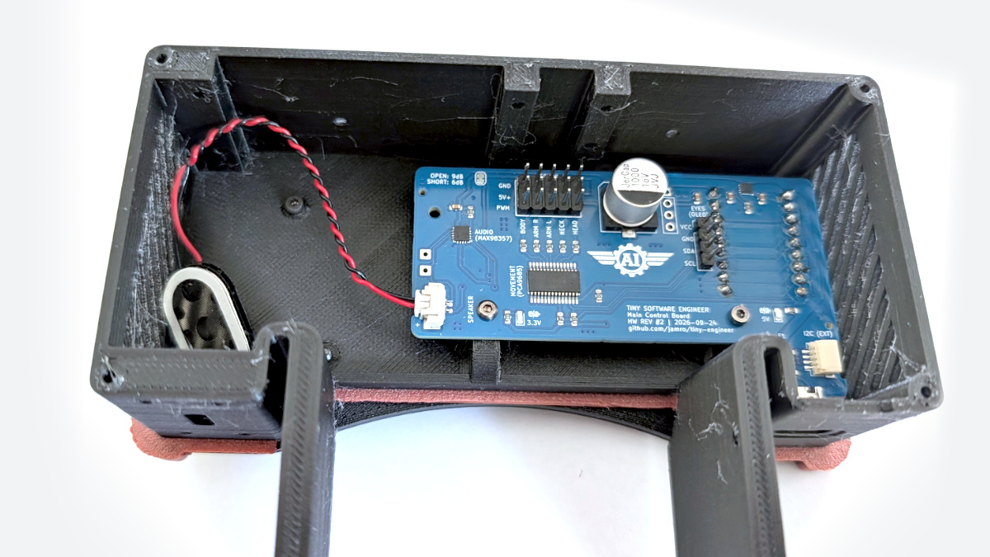
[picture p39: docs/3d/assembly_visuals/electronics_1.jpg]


## ESP32, power/AP smoke test, and `LampBase`

1. Seat the **ESP32-C3-Zero** in the opening in the desk top from above. The pins must pass through the holes in the top; the module should sit flush in the recess and not stick up above the desk surface.
2. From underneath, connect the gold-pin jumper cables to the ESP32.
3. **Power/AP smoke test** (optional but recommended) before locking the module in:
   - Confirm every wire is on the correct pin ([wiring](../hardware/wiring.md)). Servo plugs and the OLED come later.
   - Firmware should already be on the board (flashed before servo centering).
   - Apply power. The ESP32 LED should light and the board should start the **setup access point** for configuration.
   - If that looks good, **disconnect power**.
4. Place the printed `LampButton` under `LampBase` so it can press the ESP32 **reset** button from above — keep that access easy.
5. Orient `LampBase` so its opening sits over the ESP32 status LED.
6. Fasten `LampBase` to the desk with **two M2 screws** (M2×8 mm works). This also holds the ESP32 from above.

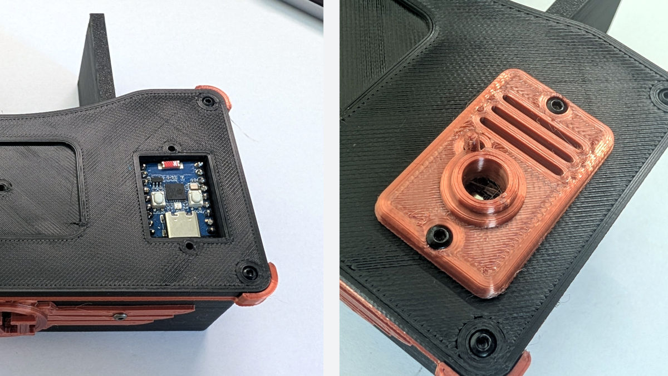
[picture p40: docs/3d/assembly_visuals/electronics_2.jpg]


## Next

Continue at [assembly §14](assembly.md#14-desk-props--laptop-mug-bell).

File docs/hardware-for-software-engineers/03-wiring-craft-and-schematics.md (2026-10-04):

# Wiring craft and schematics

Software has stack traces. Hardware has smoke. Most beginner failures aren't mysterious — they're a loose GND, swapped data lines, or a wire that pulled out when you closed the case. This chapter is about making connections you can trust and reading the diagram — Tiny Engineer's drawing is the practice artifact.

---

## Dupont / jumper — the connector this project uses

**Dupont** (jumper) = plastic housing on a pin header. One wire, one pin. That's the whole connector story here.

This build uses Dupont on **servos**, **OLED**, and **ESP32** so those parts unplug and swap if something dies. Servo cables already end in a 3-pin plug (signal / +5 V / GND — often yellow, red, brown; **verify your batch**). That plug seats on Dupont-style headers.

> **If you've written backend code…** Dupont is like a typed port: one pin, one job. Read the silkscreen. Wrong hole is a type error with smoke.

---

## Breadboard vs permanent wiring

**Breadboard** — spring clips, no solder. Great for blinking an LED. Wires pop out. Too bulky for this robot.

The default build plugs the ESP32, OLED, servos, and speaker into the [main control board](../hardware/main-control-board.md). The soldered harness below is the **advanced** path — extra modules the board does not support ([wiring.md](../hardware/wiring.md), [shopping](../shopping.md#advanced-extra-modules)). Those joints have to survive a small printed body. Vibration and tight space kill breadboard builds.

**Practical split (modular):**
- **Solder** the boards that stay in the robot: USB-C breakout, PCA9685 servo driver, audio amp, and the power/signal harness between them
- **Dupont** to ESP32, OLED, and servos — replaceable without a soldering iron
- Wire and **verify on the desk** (boot, I2C, one servo) **before** seating the electronics in the chest. Debugging inside a closed chest is miserable

The Waveshare **ESP32-C3-Zero** used here ships with **male pins already soldered**. On the modular path you still solder everything else that doesn't come with headers you can plug into: USB socket/breakout, servo controller, audio board, and the wires that join those modules.

---

## Strain relief and color

Don't tug on solder joints. Zip-tie or clip USB and servo cables so a yank hits the tie, not the pad.

Color is habit, not law: red ≈ positive, black/brown ≈ GND, yellow/orange/green ≈ signal. **Trust labels and a multimeter, not memory.**

---

## Reading schematics and block diagrams

You don't need a full EE schematic. You need the **block diagram** mindset:

- **Boxes** = modules (ESP32, PCA9685, OLED, amp)
- **Lines** = nets (SDA, SCL, 5V, GND)
- **Same net name** = must be connected together

Tiny Engineer's map: [Tiny Engineer.drawio.png](../wiring/Tiny%20Engineer.drawio.png).

> **If you've written backend code…** The PNG is an architecture diagram. [wiring.md](../hardware/wiring.md) is the connection table. [pinout.md](../hardware/pinout.md) is GPIO allocation. Same system, three views.

**How to use the diagram:**
1. Find the ESP32 box — trace I2C to PCA9685 and OLED
2. Trace 5 V from USB breakout to each power consumer
3. Trace 3.3 V from ESP32 to logic VCC pins
4. Confirm GND stars at the USB breakout and fans out

Don't memorize — **trace the path** for whatever you're debugging.

---

## Soldering: enough to not fear it

You will solder. The ESP32 headers are already done; USB, PCA9685, audio, and the interconnects are not.

Basics:
- **Iron** ~350°C for lead-free (follow your solder's label)
- **Tin the pad and the wire**, then join — don't dump a blob on one side
- **Continuity check** after — multimeter beep between pad and wire end

Bad solder looks dull and grainy (cold joint). Good joint is shiny and concave. YouTube "through-hole soldering" beats a paragraph here.

---

## What not to do on first power-up

- Don't power servos before common GND is verified
- Don't connect MAX98357A **SPK−** to GND (bridge-tied load — see [Ch. 04](04-buses-and-protocols.md))
- Don't force a tight 3D-printed pocket onto a servo — ream or reprint instead

Assembly checks before first power: [main-control-board.md](../hardware/main-control-board.md). Advanced harness: [wiring.md](../hardware/wiring.md) — read that when you're actually wiring, not this chapter.

---

## In Tiny Engineer

The default connect checklist is [main-control-board.md](../hardware/main-control-board.md). The drawio and the steps below are the advanced breakout harness: [Tiny Engineer.drawio.png](../wiring/Tiny%20Engineer.drawio.png) and [wiring.md](../hardware/wiring.md). This guide doesn't duplicate the connection table.

**Desk smoke order** (wiring mindset — after wire + flash, before the mechanical run):
1. USB power + GND only → ESP32 boots (LED, serial)
2. Add I2C devices → serial shows PCA9685 found
3. Add one servo on one channel → `/test/servo` or setup AP **Move all to 90°**
4. Add audio and OLED as you wire the rest of the harness
5. Then open [assembly.md](../3d/assembly.md) from §1 (one mechanical run). Seat the harness with [assembly-modular.md](../3d/assembly-modular.md), which replaces assembly §12–§13.

**OLED naming trap:** this build uses the [Waveshare 0.91inch OLED Module](https://www.waveshare.com/0.91inch-oled-module.htm), which labels the clock pad **SCL**. Many clone 0.91" boards print **SCK** on that same I2C clock pin — not SPI. The wiring PNG may still say **SCK**.

---

**Next:** [Buses and protocols](04-buses-and-protocols.md)

**Reference:** [hardware/main-control-board.md](../hardware/main-control-board.md) · [hardware/wiring.md](../hardware/wiring.md) · [wiring/Tiny Engineer.drawio.png](../wiring/Tiny%20Engineer.drawio.png)

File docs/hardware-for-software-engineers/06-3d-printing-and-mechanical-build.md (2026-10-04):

# 3D printing and mechanical build

Software lives in repos; hardware lives in **enclosures**. 3D printing is how you turn CAD into a physical body — layer by layer, with tolerances that bite if you ignore them. If you've never printed, this chapter is the missing semester: materials, fit, CAD source, and not destroying a servo by forcing it into a tight pocket. **Tiny Engineer** is the case study; the skills transfer to any printed mount or case.

---

## FDM printing in 60 seconds

**FDM** (Fused Deposition Modeling) — the common hobby printer type — melts plastic filament layer by layer.

Knobs that matter:

| Parameter | Typical starting point | What it affects |
| --- | --- | --- |
| **Layer height** | **0.16 mm** (used for the tested prints) | Surface quality vs speed |
| **Infill** | 20–30% structural | Strength vs print time |
| **Orientation** | As in the `.3mf` | Overhangs; supports (see below) |
| **Material** | **PLA** is enough; PETG also works | Ease vs toughness |

### Supports

Plastic cannot print in mid-air. An **overhang** (a surface that sticks out with nothing under it) needs **supports** — extra throwaway plastic the slicer builds like scaffolding, then you snap or dissolve off.

Supports leave scars, use filament, and make small holes and servo pockets messy.

**This project's parts are designed and oriented so they print with no supports.** Keep the `.3mf` orientation. Rotate a part "to look nicer on the bed" and you may suddenly need supports and get ugly undersides.

### What printer

All parts were printed and test-fitted on a **Creality Ender 3 V3 SE**. You should be able to print them on **any FDM printer** that can run PLA (or PETG) at typical hobby settings — the files are not locked to that machine.

No printer? You can [order the aggregated part sets from a third-party service](../3d/order-parts.md) instead of printing at home, then continue with assembly.

---

## Materials: PLA vs PETG

**PLA is sufficient** for the whole robot — desk use, indoor, this design. **PETG also works** if that's what you have (tougher, a bit stringier to print). Pick one spool if you care about color match.

| Material | Use here |
| --- | --- |
| **PLA** | Default. Fine for servo pockets, chair, desk, props |
| **PETG** | Also fine. Slightly stronger; not required |

Antenna zone: keep plastic thin/light near the ESP32 ceramic antenna. No metal paint, no foil wrap "for aesthetics."

---

## Tolerance and "it doesn't fit"

The models are **prepared with clearance** so printed parts and hardware (servos, screws) are meant to **fit together** without sanding as the happy path. 3D printing is still approximate — holes shrink, first layers bulge ("elephant's foot"), printers vary.

**If a servo doesn't slide in:**
- Don't force it — gears aren't meant to take press-fit stress
- Ream with a drill bit by hand, or
- Sand lightly, or
- Open the pocket in CAD and re-export

> **If you've written backend code…** Printed holes are like JSON numbers — `2.0` isn't exactly 2.0 after float serialization. These files already budget slack; a badly calibrated printer can still eat it.

**Screws:** assembly uses **M2** screws that thread directly into the printed plastic — no glue, no heat-set inserts. Shopping list (M2×4 / ×8 / ×16 + nuts; same lengths for every servo preset) lives in the [3D models README](../../3d_models/README.md#screws). Join order: [assembly guide](../3d/assembly.md). Test fit as you go.

**If M2 screws feel loose (slide instead of cutting a thread):** print tolerances ate the pilot. Print [`ScrewSizingTest.3mf`](../../3d_models/README.md#print-first) first (alongside [`ServoSizingTester`](../../3d_models/README.md#print-first)), pick the labeled hole that bites firmly, set Fusion `screw_thread_diameter` to that diameter, and re-export. CAD default / shipped parts use **2.1 mm**. Full write-up: [M2 screw holes](../3d/parametric-design.md#m2-screw-holes).

---

## Editing the CAD — Fusion 360

### Source vs export

| File | What it is |
| --- | --- |
| [`cad/TinyEngineer.f3d`](../../3d_models/cad/TinyEngineer.f3d) | **Parametric source** — full assembly in Autodesk Fusion |
| [`3d_models/parts/{servo_id}/3mf/*.3mf`](../../3d_models/parts/) | **Exported meshes** — what the printer eats |

> **If you've written backend code…** `.f3d` is the repo. `.3mf` is the release binary. Don't edit `.3mf` as source — edit Fusion, re-export.

### When to open Fusion

- Servo pocket too tight/loose after first print
- Different micro servo dimensions (use a [`servos.json`](../../3d_models/fusion/TinyEngineerTools/servos.json) preset, or add one)
- Cable routing channel for your wiring harness
- Antenna keep-out adjustment
- Desk/chair scale for your desk

Parts use **M2** screws (`screw_thread_diameter` pilot). Servo pockets follow the selected Fusion preset, not one fixed body size. Swapping servos means picking a preset (or adding one) and reprinting — not just firmware. Servo user parameters, screw pilots, the Fusion add-in (configurator + exporter), and how to add a preset: [parametric design](../3d/parametric-design.md).

### Export workflow

1. Open `TinyEngineer.f3d` in Fusion (free personal license exists)
2. Apply a servo preset; set `screw_thread_diameter` from your [`ScrewSizingTest`](../../3d_models/README.md#print-first) if needed
3. Export with **Tiny Engineer Parts Exporter** into `parts/{servo_id}/3mf/` (see [parametric design](../3d/parametric-design.md))
4. Print testers first, then the rest, and test fit

Manual single-body export is fine for a one-off tweak; keep the file under that servo’s `3mf/` folder, not a flat `3d_models/parts/` dump.

Alternatives (FreeCAD, Onshape) can work but project source is Fusion.

---

## Mechanical assembly principles

Step-by-step SOP: [assembly.md](../3d/assembly.md). Use that guide for the build sequence; principles below cover key failure modes.

### Servo installation

- **Orientation matters** — spline exit direction must match linkage. Check before screwing pocket closed
- **Screw horn with servo at center** — boot firmware or `/test/servo` to 90° first
- **Don't over-tighten horn screw** — strips plastic hub

### Range of motion before closing shell

Command each joint through safe range ([robot-movement.md](../robot-movement.md)). Listen for buzzing (stall). Adjust horns or setup-AP min/max (NVS) before trapping servos in plastic.

### USB and service access

Leave the main control board USB-C reachable for reflash. You'll flash again. Trust me. The advanced path uses a 5993 in that same role — [wiring.md](../hardware/wiring.md).

### Antenna clearance

ESP32-C3-Zero ceramic antenna needs air. Don't bury it against metal or a thick plastic wall. Wi-Fi is the control plane for your agent.

### No glue policy

Screws only — disassembly for fixes. Like modular monolith vs ball of mud.

### Desk scene

Chair, desk, laptop, bell, lamp, mug — cosmetic storytelling. Print order doesn't matter much; prioritize robot body + servos for bring-up.

Part list: [3d_models/README.md](../../3d_models/README.md).

---

## Print while you wait — parallel path

Electronics can ship slow. Start printing **structural parts** (chest, head, chair) while reading [Ch. 04](04-buses-and-protocols.md). Connect and smoke at checklist [§3–4](../getting-started.md#3-connect) — still on the desk — then one assembly run. Parallelism beats serial idle time.

---

**Next:** [Power budgets and safety](07-power-budgets-and-safety.md)

**Reference:** [assembly.md](../3d/assembly.md) · [3d_models/README.md](../../3d_models/README.md) · [cad/TinyEngineer.f3d](../../3d_models/cad/TinyEngineer.f3d) · [parametric design](../3d/parametric-design.md) · [robot-movement.md](../robot-movement.md)

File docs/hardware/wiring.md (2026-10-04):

# Modular wiring (advanced)

The default build uses the [main control board](main-control-board.md). This page is for adding modules that board does not support: a separate PCA9685 breakout, a MAX98357A breakout, and an Adafruit 5993 USB-C breakout.

Build the harness **on the desk** ([getting-started](../getting-started.md) — after print, before flash). Seat it with [assembly-modular.md](../3d/assembly-modular.md), which replaces [assembly §12–§13](../3d/assembly.md#12-electronics-inside-the-desk).

**Why these nets exist:**

- Two voltage rails: **5 V** for servos and the amp; **3.3 V** for ESP32 GPIO, PCA9685 **VCC**, and OLED. Never jumper those together.
- PCA9685 **VCC** is logic; **V+** is servo power. Same chip, two jobs.
- OLED and PCA9685 share one I2C bus (SDA/SCL).
- Audio is I2S into the MAX98357A; the speaker is **BTL** — **SPK− is not ground**.
- Every module shares **GND**.

**Connect in this order (power last):**

1. Common **GND** to every module.
2. Signal wires: I2C (SDA/SCL), I2S (BCLK/LRC/DIN), USB D+/D−, PCA9685 OE (GP5 → OE).
3. Logic **3V3**: ESP32 **3V3** → PCA9685 **VCC** and OLED **VCC**.
4. **5 V** last: USB VBUS → ESP32 **5V**, PCA9685 **5V**, MAX98357A **Vin**. Leave servo leads unplugged until centering.

Source of truth for *what is connected to what*: [`docs/wiring/Tiny Engineer.drawio.png`](../wiring/Tiny%20Engineer.drawio.png) ([`.drawio`](../wiring/Tiny%20Engineer.drawio)).

Firmware GPIO numbers: [`include/pins.h`](../../include/pins.h) / [pinout.md](pinout.md). Diagram labels pads **GP0**…**GP21**; those are the same pins as GPIO0…GPIO21.

Diagram colour: **red** = 5 V, **blue** = GND, thin wires = signals.

## Pin names as drawn

| Diagram label | Same net / meaning |
| --- | --- |
| USB **5V** | +5V rail (Adafruit 5993 **VBUS**) |
| USB **GND** | Common **GND** |
| USB **D−** / **D+** | 5993 data → ESP32 **GP18** / **GP19** (may be omitted on PNG) |
| ESP32 **GP0** | GPIO0, I2C **SDA** |
| ESP32 **GP1** | GPIO1, I2C **SCL** |
| ESP32 **GP2** | GPIO2, I2S **BCLK** |
| ESP32 **GP3** | GPIO3, I2S **WS/LRC** |
| ESP32 **GP4** | GPIO4, I2S **DIN** |
| PCA9685 **5V** | Servo-power *input* from USB 5V |
| PCA9685 **V+** | Servo-power *output* to servo 5V |
| PCA9685 **VCC** | Logic **3V3** |
| OLED **SCL** | I2C **SCL** (Waveshare silkscreen; PNG may say **SCK**) |
| MAX98357A **Vin** | Amp **+5V** (**VIN**) |
| MAX98357A **LRC** | **WS/LRC** |

On Adafruit PCA9685, header/terminal **V+** is normally the same servo rail as the diagram’s PCA9685 **5V** pad. Do **not** treat PCA9685 **5V** as **VCC**.

## Connection table (as drawn)

| From | Pin | To | Pin | Purpose |
| --- | --- | --- | --- | --- |
| USB (5993) | 5V / VBUS | ESP32-C3-Zero | 5V | Board 5 V in |
| USB (5993) | 5V / VBUS | PCA9685 | 5V | Servo-rail in |
| USB (5993) | 5V / VBUS | MAX98357A | Vin | Amp power |
| USB (5993) | GND | ESP32-C3-Zero | GND | Common ground |
| USB (5993) | GND | PCA9685 | GND (logic/header side) | Common ground |
| USB (5993) | GND | OLED | GND | Common ground |
| USB (5993) | GND | MAX98357A | GND | Common ground |
| USB (5993) | D− | ESP32-C3-Zero | GP18 | Native USB D− (flash / CDC) |
| USB (5993) | D+ | ESP32-C3-Zero | GP19 | Native USB D+ (flash / CDC) |
| ESP32-C3-Zero | 3V3 | PCA9685 | VCC | PCA9685 logic |
| ESP32-C3-Zero | 3V3 | OLED | VCC | OLED power |
| ESP32-C3-Zero | GP0 | PCA9685 | SDA | I2C data |
| ESP32-C3-Zero | GP0 | OLED | SDA | I2C data (shared) |
| ESP32-C3-Zero | GP1 | PCA9685 | SCL | I2C clock |
| ESP32-C3-Zero | GP1 | OLED | SCL | I2C clock (shared; Waveshare silkscreen **SCL**; PNG may say **SCK**) |
| ESP32-C3-Zero | GP2 | MAX98357A | BCLK | I2S bit clock |
| ESP32-C3-Zero | GP3 | MAX98357A | LRC | I2S word select |
| ESP32-C3-Zero | GP4 | MAX98357A | DIN | I2S data |
| PCA9685 | PWM | Servo | SIG | Servo PWM |
| PCA9685 | V+ | Servo | 5V | Servo power |
| PCA9685 | GND (servo side) | Servo | GND | Servo ground |

**All modules must share a common ground.** USB GND is the star in the drawing (ESP32, PCA9685 header, OLED, MAX98357A). Servo GND returns through PCA9685 servo-side GND, which is the same ground net.

> [!WARNING]
> Never power the servos from the ESP32 3.3 V regulator. Diagram: servo **5V** ← PCA9685 **V+**; PCA9685 **VCC** ← ESP32 **3V3** only.

## Power (as drawn)

```
USB 5V
  → ESP32 5V
  → PCA9685 5V
  → MAX98357A Vin

PCA9685 V+
  → Servo 5V
```

```
ESP32 3V3
  → PCA9685 VCC
  → OLED VCC
```

```
USB GND
  → ESP32 GND
  → PCA9685 GND (header)
  → OLED GND
  → MAX98357A GND

PCA9685 GND (servo header)
  → Servo GND
```

USB block in the drawing is the Adafruit **5993** — robot **power** (VBUS/GND) and, when wired, **programming** (D+/D− → GP19/GP18). The PNG may show only 5V/GND; data wires are required for the single-USB design. See [interfaces.md](interfaces.md).

## I2C (as drawn)

Shared bus:

- ESP32 **GP0** → PCA9685 **SDA** and OLED **SDA**
- ESP32 **GP1** → PCA9685 **SCL** and OLED **SCL**

Addresses (firmware, not on the drawing): PCA9685 `0x40`, OLED `0x3C`. See [interfaces.md](interfaces.md).

## I2S (as drawn)

- ESP32 **GP2** → MAX98357A **BCLK**
- ESP32 **GP3** → MAX98357A **LRC**
- ESP32 **GP4** → MAX98357A **DIN**
- USB **5V** → MAX98357A **Vin**
- USB **GND** → MAX98357A **GND**

Drawn MAX98357A pads: **Vin**, **GND**, **BCLK**, **LRC**, **DIN** only.

## PCA9685 → servo (as drawn)

One generic **Servo** block:

| Servo | PCA9685 |
| --- | --- |
| SIG | PWM |
| 5V | V+ |
| GND | GND |

Firmware drives **channels 0–4** (`SERVO_SPECS` / `SERVO_HEAD`…`SERVO_BODY`). The drawing does not number the PWM header. Channel → joint: [robot-movement.md](../robot-movement.md) / [`include/servos.h`](../../include/servos.h).

## Pads drawn with no wires

ESP32-C3-Zero, unused in the PNG:

**GP6, GP7, GP8, GP9, GP10, GP20, GP21**

Wire **GP5** → PCA9685 **OE** (`PCA9685_OE_PIN`; active LOW). The base PNG may omit that wire — add it on the breadboard and on the Adafruit breakout OE pin. GP9 = BOOT, GP10 = onboard WS2812. GP18/GP19 = native USB — wire from 5993 D−/D+ even if the base PNG omits them. See [pinout.md](pinout.md).

MAX98357A **GAIN** / **SD** not wired (breakout defaults). **SPK+** / **SPK-** not drawn.

## Not on the drawing

Still part of the selected hardware; do not invent extra ESP32 GPIO for them.

| Item | Rule |
| --- | --- |
| Speaker | Terminals → MAX98357A **SPK+** and **SPK-** only |
| 4 extra analog micro servos | Same 3-wire pattern as the drawn servo, on PCA9685 PWM 0–4 |
| Adafruit 5993 D+/D− | Wire to ESP32 **GP19** / **GP18** for flash and CDC (single-USB design) |
| PCA9685 OE | Wire ESP32 **GP5** → PCA9685 **OE** (active LOW) |
| MAX98357A GAIN / SD | Not wired; leave breakout defaults |

> [!WARNING]
> MAX98357A output is BTL. **SPK- is not ground.** Never tie SPK- or SPK+ to GND. Never drive the speaker from ESP32 GPIO.

## USB connector (5993)

On this path the robot uses **one** USB-C connector: the Adafruit 5993.

| Net | 5993 | ESP32 |
| --- | --- | --- |
| +5V | **VBUS** | **5V** pad (and the shared +5V rail) |
| GND | **GND** | **GND** |
| USB D− | **D−** | **GPIO18** (native USB D−) |
| USB D+ | **D+** | **GPIO19** (native USB D+) |

| Connector | Role |
| --- | --- |
| Adafruit **5993** | Only robot USB-C: **VBUS/GND** (power) + **D+/D−** → GP19/GP18 (flash / serial CDC) |
| ESP32-C3-Zero onboard USB-C | Leave **unused** when 5993 data is wired (avoids dual 5 V feed) |

That one cable supplies robot power and programming / serial CDC (`ARDUINO_USB_MODE=1`, `ARDUINO_USB_CDC_ON_BOOT=1`, monitor 115200). For early bare-module flashing before 5993 data is wired, the onboard port is fine.

Adafruit 5993 is a USB Type-C vertical breakout (downstream). Two 5.1 kΩ CC resistors ask the upstream port for **5 V / up to ~1.5 A**. Whether 1.5 A actually arrives depends on the charger/port. Five HD-1370A servos at stall (~1.3 A @ 4.8 V) plus the rest of the robot leaves little safety margin on a 1.5 A USB source. SG90 stall is typically higher still.

- **5 V / ≥ 2 A**, with extra margin if several servos can move **while audio plays**.
- The 5993 does not raise the current ceiling above what the source and CC advertisement allow.
- The 5993 is **not** USB-PD voltage conversion. Feed it 5 V USB, or bypass it with a dedicated 5 V / ≥2 A PSU on the +5V and GND rails.

The drawing may show USB **5V** / **GND** only; also wire **D+/D−**.

See [interfaces.md](interfaces.md), [power.md](power.md).

## Assembly checks

1. Every **GND** in the PNG is one net (USB, ESP32, PCA9685 both sides, OLED, MAX98357A, servo).
2. PCA9685 **VCC** ≈ 3.3 V, PCA9685 **5V** / **V+** ≈ 5 V, those two nets **not** shorted.
3. OLED clock wire lands on Waveshare **SCL** (PNG may still say **SCK**).
4. I2S is GP2/GP3/GP4 → BCLK/LRC/DIN, not swapped with I2C.
5. Speaker (if fitted) is only SPK+/SPK-, which are **not** in the PNG.

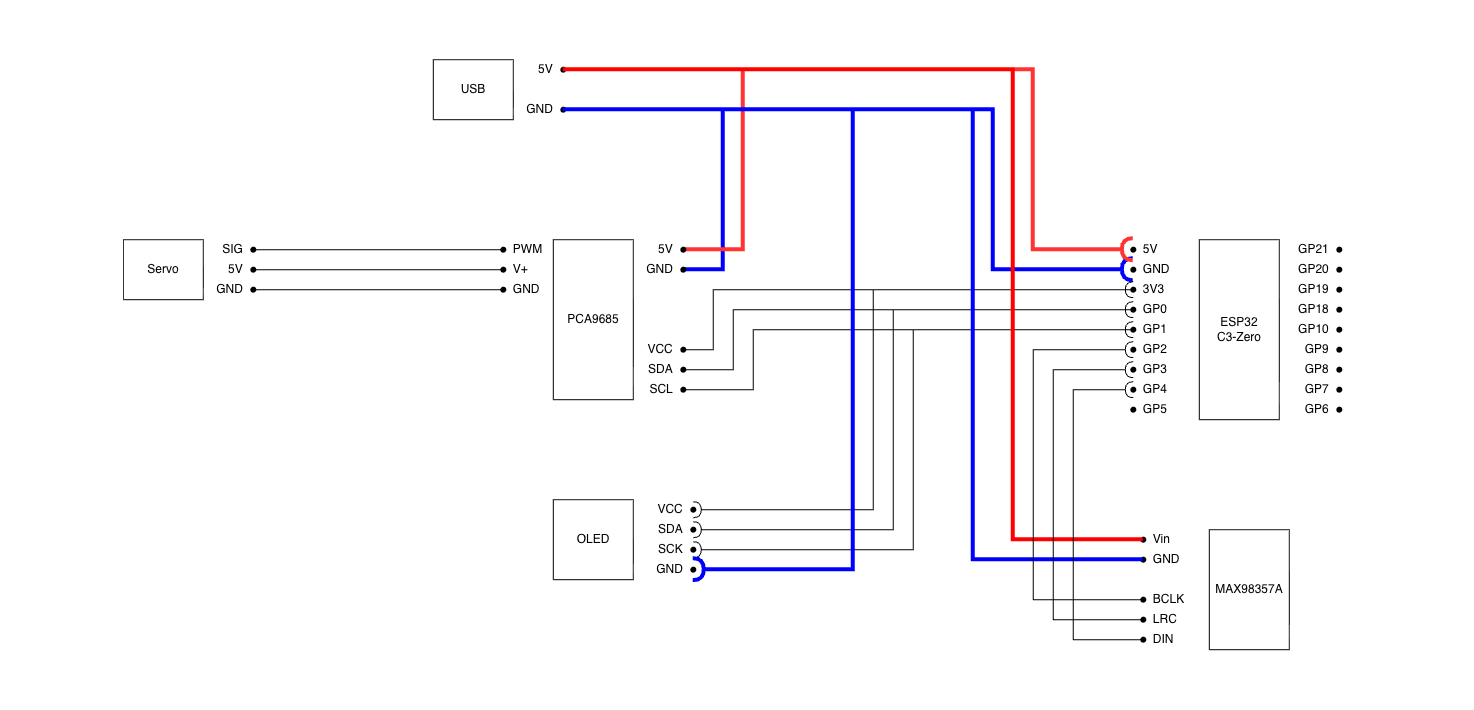
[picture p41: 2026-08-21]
docs/wiring/Tiny Engineer.drawio.png

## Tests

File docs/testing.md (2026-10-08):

# Tests

Host checks. These commands do not flash the board. GitHub Actions on `main` and PRs runs these same commands (firmware, packages, and PCB). On-device hardware: [hardware/testing.md](hardware/testing.md).

## Firmware

Unity on the host. Compiles `src/settings/validate.cpp` plus header-only helpers such as [`include/servos.h`](../include/servos.h).

```bash
pio test -e native
python3 scripts/test_audio_pack.py
```

`pio run` builds firmware. Native tests are **`pio test -e native`**, not `pio run -e native`. `scripts/test_audio_pack.py` checks the stock WAV copy and mod overlay (no PlatformIO, no hardware). On GitHub Actions the firmware job also runs `pio run -t buildfs` and uploads `bootloader.bin`, `partitions.bin`, `firmware.bin`, and `littlefs.bin` as the `firmware-<sha>` artifact.

## OLED expressions

The optional [expression library](../lib/TinyEngineerExpressions/README.md) has deterministic asset checks and native renderer tests. These checks require Node 18+ and PlatformIO; they do not access hardware. On the robot, enable those faces with Config / `eyes_style=kaomoji` (default remains `classic`).

```bash
node scripts/expressions/generate.js --check
node scripts/expressions/test-assets.js
pio test -e native
pio run -e expression-demo
```

The `expression-demo` environment builds a separate OLED-only application without changing the default robot build. For a later bench test, follow its [wiring and upload notes](../lib/TinyEngineerExpressions/README.md#standalone-oled-demo), leave the separate servo supply off, and observe all 16 faces through a complete 48-second cycle. Report physical display results separately from host tests and compilation.

## Web UI

The control panel in [`ui/`](../ui/) is linted with [html-validate](https://html-validate.org/), ESLint, [Stylelint](https://stylelint.io/) (`stylelint-config-standard`) and Prettier. Node 20.19+ on 20.x, or 22.12+.

```bash
npm ci --prefix ui
npm run lint --prefix ui
npm test --prefix ui
npm run format --prefix ui   # apply Prettier
```

`npm test` runs [Vitest](https://vitest.dev/) in jsdom: each test loads the real `index.html`, imports the UI modules, and drives them against a fake robot that stubs `fetch` and records requests ([`ui/test/robot.js`](../ui/test/robot.js)). The tests cover the auth gate, config saving and access-token handling, the servo page range hint, and the setup wizard (step order, what each step saves, step-only calibration moves, LED order validation).

## Packages

Node 18+. No robot.

```bash
npm test --prefix packages/tiny-engineer-cli
npm test --prefix packages/tiny-engineer-cursor
npm test --prefix packages/tiny-engineer-antigravity
npm test --prefix packages/tiny-engineer-claude-code
```

## PCB

KiCad 10 (`kicad-cli`). Stdlib Python only — no pip packages. ERC (errors), DRC (errors + schematic parity), and `expected-nets.yml` for every board under `hardware/boards/`.

```bash
python3 scripts/check_pcb.py
```

Optional: `python3 scripts/check_pcb.py main-control-board --report-dir artifacts/pcb`. Details: [pcb.md](pcb.md). On-device hardware: [hardware/testing.md](hardware/testing.md).

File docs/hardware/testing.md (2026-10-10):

# Hardware testing

Firmware is [`src/main.cpp`](../../src/main.cpp). Boot **inits** hardware and starts HTTP. Demos (OLED, tones, servo sweep) run on demand via REST. Helpers:

- [`src/hardware/rgb.cpp`](../../src/hardware/rgb.cpp)
- [`src/display/oled.cpp`](../../src/display/oled.cpp) (init/boot/test: `oled_init.cpp`, `oled_boot.cpp`, `oled_test.cpp`)
- [`src/network/wifi_connect.cpp`](../../src/network/wifi_connect.cpp)
- [`src/audio/audio.cpp`](../../src/audio/audio.cpp)
- [`src/hardware/pca9685_servos.cpp`](../../src/hardware/pca9685_servos.cpp)
- [`src/http/http_server.cpp`](../../src/http/http_server.cpp), [`src/http/test_handlers.cpp`](../../src/http/test_handlers.cpp)

Constants: [`include/pins.h`](../../include/pins.h). Wi-Fi credentials are saved in NVS and configured only in setup AP mode (first boot, or after factory reset + power-cycle). Servo min/max, RGB LED mapping (`rgb_order`), and OLED rotation (`oled_rotate_180`) are also setup-AP-only; factory reset keeps them.

Stock flash: **[Web flash](https://jamro.github.io/tiny-engineer/flash/)**. Build from source / serial (115200): [flash.md](../flash.md) (Advanced: PlatformIO — `pio run`, `pio run -t upload`). Physical board is **Waveshare ESP32-C3-Zero**; PlatformIO env name is `esp32-c3-devkitm-1`.

## What boot covers

| Subsystem | How |
| --- | --- |
| Built-in WS2812 | Green ready (GPIO10) |
| I2C init | `Wire.begin` on GPIO0/GPIO1 |
| PCA9685 | Probe `0x40` early; OE HIGH during init, park neutral, then OE LOW (`PCA9685_OE_WIRED`) |
| OLED | Probe `0x3C`, init (optional) |
| Wi-Fi | STA connect from saved NVS credentials, or setup AP `TinyEngineer-XXXX` when unset/failed; mDNS `{hostname}.local` after STA connect |
| MAX98357A / I2S | `I2S.begin` 22.05 kHz 16-bit stereo |
| Servos | Smooth move to mid (or sleep pose) at 35°/s |
| HTTP | Port 80 when STA connected, or on setup AP at `192.168.4.1` |
| Success | Dim green RGB during init; then animation LED (see below) |
| Fatal init failure | Red blink code on the WS2812 (see below) |

## Boot-failure blink codes

A fatal init failure halts boot and blinks the onboard WS2812 red. The number of
flashes before the long gap identifies the subsystem:

| Blinks | Meaning |
| --- | --- |
| 1 | PCA9685 not found on I2C `0x40` |
| 2 | MAX98357A / I2S init failed |

Each flash is 300 ms on, 300 ms off; the gap between repeats is 3 s, so the start of a
cycle is easy to find. Serial carries the same message, but the blink code is readable
with no cable attached — and with `serial_log` off (the default) the serial line is
silent, which makes the LED the only signal a first-boot board gives you.

## Expected boot sequence

1. Serial banner `TINY ENGINEER`, then the firmware version string (`v0.1.0`, or a `git describe` form such as `v0.1.0-82-g7c79b83`)
2. `Starting I2C` / `SDA = GP0` / `SCL = GP1`
3. `Checking PCA9685 at 0x40...` → **must** succeed; all channels parked at mid
4. `Checking OLED at 0x3C...` → found or `ERROR: OLED not found` (continues)
5. Settings load from NVS (`loading` = `progress` or `sleep_inertia`)
6. **Progress loading (default):** OLED progress steps (Display → WiFi → Servos → Audio → Storage → Ready), then large full-width IP (or `No IP`) for 3 s, then idle eyes
7. **Sleep inertia loading:** wakeup frame 0 during init (classic: closed lids; cover: black halves; kaomoji: Sleepy; dots: no circles). Smooth move to sleep pose if `welcome` is on. After init, wake plays from t=0: slow eye open + blinks (~5.5 s). Head/neck wave only if `welcome` is on; otherwise eyes only
8. `WIFI SETUP` on serial — connect OK + IP, open setup AP, or saved credentials failed (setup AP for reconfiguration)
9. `Starting MAX98357A` → `I2S OK`
10. `Centering servos` — smooth move to per-channel mid (progress path only; skipped if sleep pose already applied)
11. `ROBOT READY`
12. RGB fades to white over 1 s if `welcome` runs (Wi-Fi OK and setting enabled), or fades off if idle
13. If Wi-Fi OK: `HTTP: http://<ip>/`, `HTTP: http://tiny-engineer.local/`, and `/health` URLs on serial
14. If setup AP active: `HTTP setup: http://192.168.4.1/config` on serial; OLED rotates setup instructions

`loop()` pumps the HTTP server and updates animation RGB fades. No audio/OLED/servo/LED demos until a POST.

## Animation RGB

During normal operation the onboard WS2812 tracks the active animation (not boot green):

| Animation | LED |
| --- | --- |
| `typing`, `reading`, `thinking`, `talking`, `welcome`, `ring`, `wakeup` | White |
| `attention`, `error`, `dead` | Pulsing red (10%↔100%, 1.5 s cycle) |
| `abort` | Solid red |
| `none`, `sleep` | Off |

State changes fade over **1 s** (see [`docs/api.md`](../api.md#rgb-led)). Trigger via `POST /anim?name=…` or agent hooks / CLIs.

OLED shows matching status strings when the panel is present (progress loading: WiFi step labels; sleep inertia: eyes only).

## HTTP tests

API reference: [`docs/api.md`](../api.md).

Base URL is the board IP or `http://tiny-engineer.local` (2.4 GHz STA). Tests have side effects — use **POST**, not GET.

```bash
# Health
curl http://tiny-engineer.local/health

# Tones 500 / 700 / 1000 Hz
curl -X POST http://tiny-engineer.local/test/audio

# OLED title / HELLO / X in a box
curl -X POST http://tiny-engineer.local/test/screen

# Servos mid → +0.5 → −0.5 → mid of saved range (channels 0–4)
curl -X POST http://tiny-engineer.local/test/movement

# Onboard WS2812 R → G → B → white → off, then back to current animation LED
curl -X POST http://tiny-engineer.local/test/led

# One servo smooth move to angle (~140°/s; index 0–4, angle 0–180)
curl -X POST "http://tiny-engineer.local/test/servo?index=0&angle=90"
```

| Method | Path | Body |
| --- | --- | --- |
| `GET` | `/` | HTML endpoint index |
| `GET` | `/ui/*` | Web UI assets from LittleFS (gzip) |
| `GET` | `/auth` | Auth status (`ok`, `required`, `wifi_configured`, `provisioning`) — always public |
| `GET` | `/health` | Health JSON — full field list in [api.md](../api.md#get-health) |
| `GET` / `POST` | `/anim` | Current animation / start one (`name`, optional `interrupt`) — full params in [api.md](../api.md#post-anim) |
| `POST` | `/play` | Stream a WAV while `talking` (or `/play/{name}`) runs; answers when the clip ends — full params in [api.md](../api.md#post-play) |
| `GET` | `/settings` | Persistent settings (`sleep_timeout`, `hostname`, `volume`, `welcome`, `serial_log`, `continuous_timeout`, `loading`, `eyes_style`, `access_token_set`, `wifi_configured`, `wifi_ssid`, `wifi_password_set`, `servo_mins`, `servo_maxs`, `rgb_order`, `oled_rotate_180`) |
| `POST` | `/settings?...&wifi_ssid=&wifi_password=` | Update NVS settings; WiFi params setup-AP-only and tested before save; `reboot_required` if hostname changed |
| `POST` | `/settings?...&servo_mins=&servo_maxs=` | Servo min/max comma lists; setup-AP-only |
| `POST` | `/settings?...&rgb_order=` | WS2812 byte order (`RGB`/`RBG`/`GRB`/`GBR`/`BRG`/`BGR`); setup-AP-only; default `GRB` |
| `POST` | `/settings?...&oled_rotate_180=` | OLED 180° rotation (`0`/`1`); setup-AP-only; default `0` |
| `POST` | `/settings/reset` | Factory reset settings to defaults (clears WiFi, keeps servo ranges, RGB mapping, and screen rotation); power-cycle to reopen setup AP |
| `POST` | `/test/audio` | `{"ok":true,"test":"audio"}` after `runSoundTest()` |
| `POST` | `/test/audio/bell` | `{"ok":true,"test":"bell"}` after `playBell()` |
| `POST` | `/test/screen` | `{"ok":true,"test":"screen"}` after `runOledTest()` |
| `POST` | `/test/movement` | `{"ok":true,"test":"movement"}` after `runServoTest()` |
| `POST` | `/test/led` | `{"ok":true,"test":"led"}` after `runRgbTest()` |
| `POST` | `/test/servo?index=&angle=` | `{"ok":true,"test":"servo","index":N,"angle":A}` after `moveServoSmooth()` |
| `POST` | `/setup/servo?all=90` or `?index=&angle=` | Setup AP only; slow 0–180° move (`SERVO_CALIB_SPEED_DEG_S`) |
| `POST` | `/setup/led?color=R` / `G` / `B` or `?byte=0` / `1` / `2` / `off` | Setup AP only; light logical RGB or one WS2812 wire byte, or release hold |
| `POST` | `/setup/audio` | Setup AP only; play `welcome.wav` (`playWelcome()`) |
| `POST` | `/setup/oled?rotate_180=0` / `1` | Setup AP only; preview OLED 180° rotation (`THIS WAY UP`); omit param to restore provisioning text |

GET on a test path returns `405`. Bad `/test/servo`, `/setup/servo`, `/setup/led`, `/setup/audio`, `/setup/oled`, or `/settings` params return `400`. Missing/wrong Bearer when auth enabled returns `401`. Control APIs return `503` when WiFi credentials are not saved (`/setup/servo`, `/setup/led`, `/setup/audio`, and `/setup/oled` stay available). Unknown path returns `404`. JSON `Content-Type`. Handlers block until the test finishes; the OLED returns to `ROBOT READY` after.

HTTP runs on STA when connected, or on setup AP at `192.168.4.1` during provisioning.

## Failures

| Serial / OLED | Meaning | Check |
| --- | --- | --- |
| OLED `ERROR: OLED not found` then rest of boot runs | Nothing ACK’d at `0x3C` | OLED **VCC=3V3**, GND, SDA=GP0, **SCL**=GP1, common ground, address jumper still 0x3C |
| OLED found but `ERROR: OLED initialization failed` | ACK then `display.begin` failed | Wiring/power glitch, wrong size module, I2C noise |
| OLED shows `Join this WiFi` / AP name, then `Then open` / `192.168.4.1` | Setup AP mode active | Connect to the shown AP, open `http://192.168.4.1/config`, finish the servo + screen + LED + speaker + WiFi wizard |
| OLED `WiFi failed` then setup AP | Saved STA credentials failed | Join setup AP, open `http://192.168.4.1/config`, enter home WiFi again |
| `ERROR: PCA9685 not found` + red RGB + **hang** | Nothing ACK’d at `0x40` | PCA9685 **VCC=3V3** (not V+), GND, SDA/SCL, I2C address pads, +5V not required for the ACK but needed later for motion |
| `ERROR: I2S initialization failed` + red RGB + **hang** | `I2S.begin` failed | GPIO2/3/4 not shorted to 5V/GND; pin constants; USB CDC still alive so you can read the line |
| I2S OK but `POST /test/audio` is silent | Amp or speaker | MAX98357A **Vin**=USB 5V, GND, GP2/3/4 → BCLK/LRC/DIN, speaker on **SPK+ / SPK-** (not on the PNG, not GND) |
| Servos silent / twitch / ESP32 resets during `POST /test/movement` | Power or SIG | **V+** is +5V, SIG on ch 0–4, **common GND**, supply current — see [power.md](power.md) |
| RGB never goes green | GPIO10 LED path | Board is C3-Zero (LED on GPIO10). Do not expect an external NeoPixel |

OLED absence and Wi-Fi failure are **soft** fails. PCA9685 and I2S failures **halt** in `while (true)`.

## Power during the servo test

All five servos move together on `POST /test/movement`. A weak USB port often dies **here**. If the serial port drops exactly when that POST runs: treat as brownout, not a PWM bug. Boot parks at each joint’s calibrated mid, which is much lighter.

## What this test does not prove

- That tuned mechanical limits match a particular physical build (start from `SERVO_SPECS`; adjust after assembly)
- BLE (out of scope)
- Speaker power rating vs max amp output
- I2C at high speed

Related: [main-control-board.md](main-control-board.md), [pinout.md](pinout.md), [servos.md](servos.md). Advanced harness: [wiring.md](wiring.md).

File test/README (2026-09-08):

# Host tests

Commands: [`docs/testing.md`](../docs/testing.md).

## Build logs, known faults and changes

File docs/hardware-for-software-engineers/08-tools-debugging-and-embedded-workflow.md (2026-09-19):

# Tools, debugging, and embedded workflow

You don't need an oscilloscope to do useful hardware. You need patience, a multimeter, serial logs, and the discipline to bisect problems like you would in production. This workflow applies to any MCU project; Tiny Engineer is what you'll bench-debug first.

---

## Minimal tool kit

| Tool | Why |
| --- | --- |
| **Multimeter** | DC voltage, continuity beep |
| **USB cable (data)** | Charge-only cables cause "upload failed" existential crisis |
| **5 V / ≥ 2 A supply** | Known-good power |
| **Screwdrivers** | M2 screws, horn screws |
| **Soldering iron** (optional) | If your wiring isn't all Dupont |
| **Zip ties / tape** | Strain relief |

Nice later: helping hands, flux, desolder braid. Not day one.

---

## Multimeter — two modes you'll use

**DC voltage (V⎓):** probe between 5V and GND — should be ~5 V under load. Probe 3V3 and GND on ESP32 — ~3.3 V. If 5 V collapses when servos move, supply or wiring.

**Continuity (beep):** power **off** — verify GND nets connect, verify you're not shorting 5V to GND before first power.

You don't need to measure µs PWM pulses. If angles are wrong, suspect firmware limits or horn alignment before reaching for scope rental.

---

## Serial monitor — your stdout

```bash
pio device monitor
```

115200 baud. Boot logs tell you:
- PCA9685 found or not
- OLED found or not
- Wi-Fi state
- Init errors

> **If you've written backend code…** Serial is structured logging before structured logging existed on the device. Read it before guessing.

Upload and monitor details: [flash.md](../flash.md).

---

## PlatformIO — npm for firmware

From project root:

| Command | Does |
| --- | --- |
| `pio run` | Build firmware |
| `pio run -t upload` | Flash firmware + LittleFS (via post-script) |
| `pio run -t uploadfs` | Filesystem only — if audio silent but servos work |
| `pio device monitor` | Serial |
| `pio device list` | Find port when multiple USB devices |

`platformio.ini` is like `package.json` + Makefile — board target, libraries, upload speed.

**Board name vs physical board:** `esp32-c3-devkitm-1` is the PlatformIO target; physical board is Waveshare C3-Zero. See [Ch. 02](02-microcontrollers-and-esp32.md).

---

## Divide-and-conquer bring-up

Don't assemble everything, power on, and hope. **Bisect** like a failing integration test:

| Stage | Verify |
| --- | --- |
| 1. USB power only | ESP32 boots, serial output, dim green LED |
| 2. + I2C (PCA9685, OLED) | Serial lists devices; PCA9685 required |
| 3. + one servo on ch 0 | `/test/servo?index=0&angle=90` moves it |
| 4. + all servos | Each channel, safe ranges |
| 5. + I2S amp + speaker | Audio test endpoint or animation with sound |
| 6. + mechanical shell | Range of motion, no binding |

Failure table and expected boot sequence: [testing.md](../hardware/testing.md).

---

## HTTP test harness

Once on Wi-Fi, the robot exposes **integration-test-style endpoints**:

- `/health` — alive, CPU temp
- `/test/servo` — single joint
- Web UI — hardware tests without memorizing curl

> **If you've written backend code…** `/test/*` is a manual test harness you hit before E2E. Use it before calling the robot from Cursor hooks.

API shapes: [api.md](../api.md). Agent integration comes **after** hardware works: [integration.md](../integration.md).

---

## Hardware vs software — where to look

| Clue | Likely layer |
| --- | --- |
| Never boots, no serial | Power, USB data wiring, bricked flash |
| Boots, PCA9685 fail | I2C wiring, address, missing chip |
| Boots, resets on motion | Power supply current |
| Boots, one servo dead | That channel's signal or servo |
| Wi-Fi flaky | Antenna clearance, 2.4 GHz only, router |
| Audio silent | I2S wiring, LittleFS not uploaded, SPK+/SPK− |
| Angles wrong but motion OK | Horn alignment, safe range tuning |

When two things changed, revert one. Hardware debugging punishes batch changes like production outages.

---

## Common beginner mistakes (this project)

| Mistake | Consequence |
| --- | --- |
| Swapped SDA/SCL | No I2C devices |
| OLED clock labelled SCK on a clone (Waveshare says SCL) | Same pin — I2C SCL, not SPI |
| Servos on 3.3 V | Brownout / dead LDO |
| VCC/V+ jumpered on PCA9685 | Logic or servo damage |
| SPK− to GND | Bad audio, possible amp damage |
| Charge-only USB cable | Upload fails |
| Weak 1 A charger | Resets on animation |
| Horn aligned at wrong angle | Binding, weird rest pose |
| Antenna blocked | `.local` doesn't resolve, flaky HTTP |

---

## When things are "done enough"

You're ready for [getting-started.md § Prove it](../getting-started.md#7-prove-it) and agent hooks when:

- `/health` returns OK on Wi-Fi
- Each servo sweeps inside safe range without buzzing
- OLED shows IP (or you're OK without it)
- At least one animation with audio works
- No reset during simultaneous servo + sound

---

**Next:** [How it all fits together](09-how-it-all-fits-together.md)

**Reference:** [hardware/testing.md](../hardware/testing.md) · [getting-started.md](../getting-started.md) · [integration.md](../integration.md)

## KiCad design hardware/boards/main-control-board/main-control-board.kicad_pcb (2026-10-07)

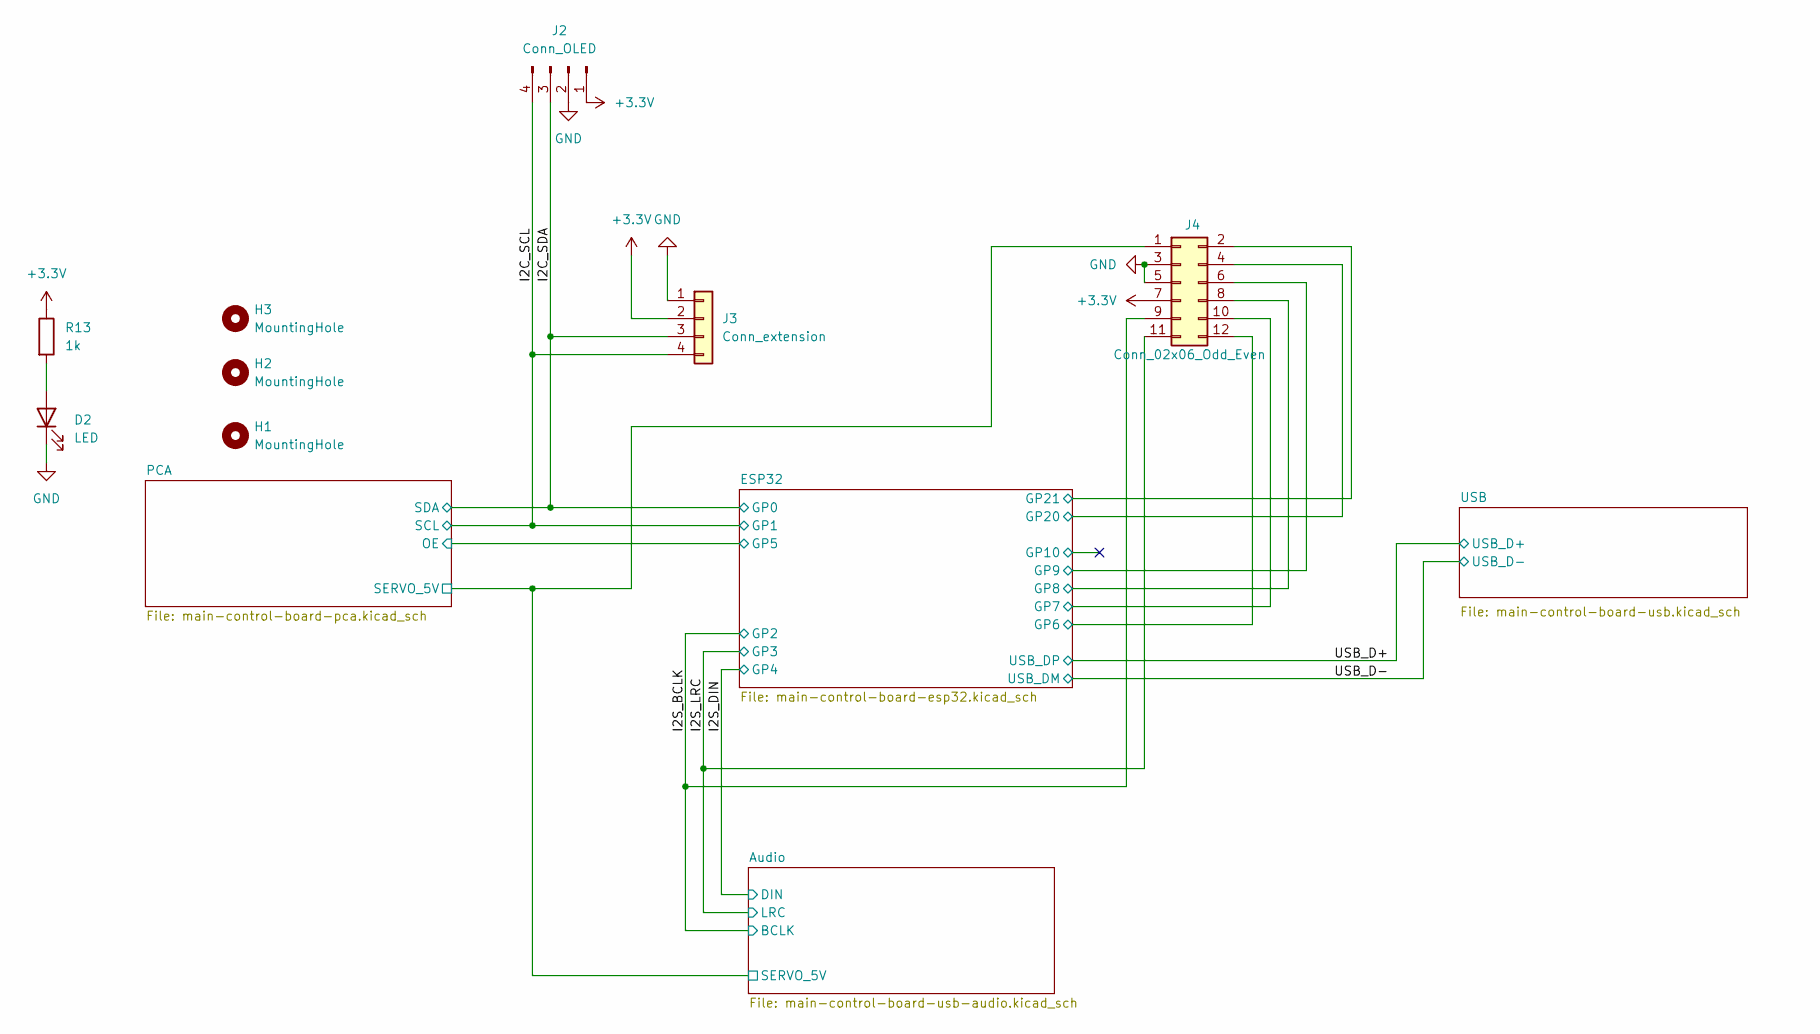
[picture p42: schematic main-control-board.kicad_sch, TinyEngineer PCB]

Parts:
D2: LED; LED_0603_1608Metric; MPN KT-0603R; LCSC Part # C2286
H1, H2, H3: MountingHole; MountingHole_2.2mm_M2
J2: Conn_OLED; PinHeader_1x04_P2.54mm_Vertical; MPN PZ254V-11-04P; LCSC Part # C2691448
J3: Conn_extension; JST_SH_SM04B-SRSS-TB_1x04-1MP_P1.00mm_Horizontal; MPN SM04B-SRSS-TB(LF)(SN); LCSC Part # C160404
J4: Conn_02x06_Odd_Even; PinHeader_2x06_P2.54mm_Vertical; MPN PM254V-12-12-H85; LCSC Part # C541855
R13: 1k; R_0603_1608Metric; MPN 0603WAF1001T5E; LCSC Part # C21190

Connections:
+3.3V: J2.1, J3.2, J4.7, R13.1; also elsewhere on the board
/ESP32/GP6: J4.12; also elsewhere on the board
/ESP32/GP7: J4.10; also elsewhere on the board
/ESP32/GP8: J4.8; also elsewhere on the board
/ESP32/GP9: J4.6; also elsewhere on the board
/ESP32/GP20: J4.4; also elsewhere on the board
/ESP32/GP21: J4.2; also elsewhere on the board
/I2C_SCL: J2.4, J3.4; also elsewhere on the board
/I2C_SDA: J2.3, J3.3; also elsewhere on the board
/I2S_BCLK: J4.9; also elsewhere on the board
/I2S_LRC: J4.11; also elsewhere on the board
/PCA/SERVO_5V: J4.1; also elsewhere on the board
GND: D2.1 (K), J2.2, J3.1, J4.3, J4.5; also elsewhere on the board
unnamed: D2.2 (A), R13.2

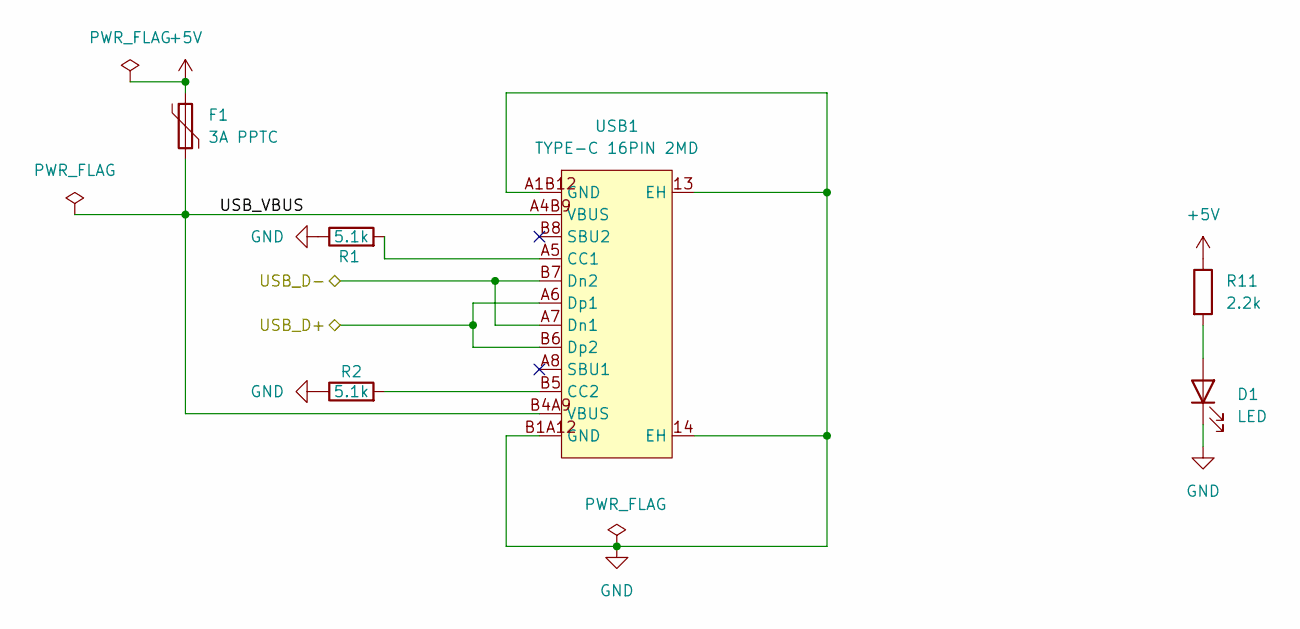
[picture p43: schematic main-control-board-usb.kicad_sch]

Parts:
D1: LED; LED_0603_1608Metric; LCSC Part # C2286
F1: 3A PPTC; Fuse_1812_4532Metric; LCSC Part # C883162
R1, R2: 5.1k; R_0603_1608Metric; LCSC Part # C23186
R11: 2.2k; R_0603_1608Metric; LCSC Part # C4190
USB1: TYPE-C 16PIN 2MD; USB-C-SMD_TYPE-C-16PIN-2MD-073; MPN TYPE-C 16PIN 2MD(073); LCSC Part # C2765186

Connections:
+5V: F1.1, R11.1; also elsewhere on the board
/USB/USB_VBUS: F1.2, USB1.A4B9 (VBUS), USB1.B4A9 (VBUS)
/USB_D+: USB1.A6 (Dp1), USB1.B6 (Dp2); also elsewhere on the board
/USB_D-: USB1.A7 (Dn1), USB1.B7 (Dn2); also elsewhere on the board
GND: D1.1 (K), R1.1, R2.1, USB1.13 (EH), USB1.14 (EH), USB1.A1B12 (GND), USB1.B1A12 (GND); also elsewhere on the board
unnamed: D1.2 (A), R11.2
unnamed: R1.2, USB1.A5 (CC1)
unnamed: R2.2, USB1.B5 (CC2)

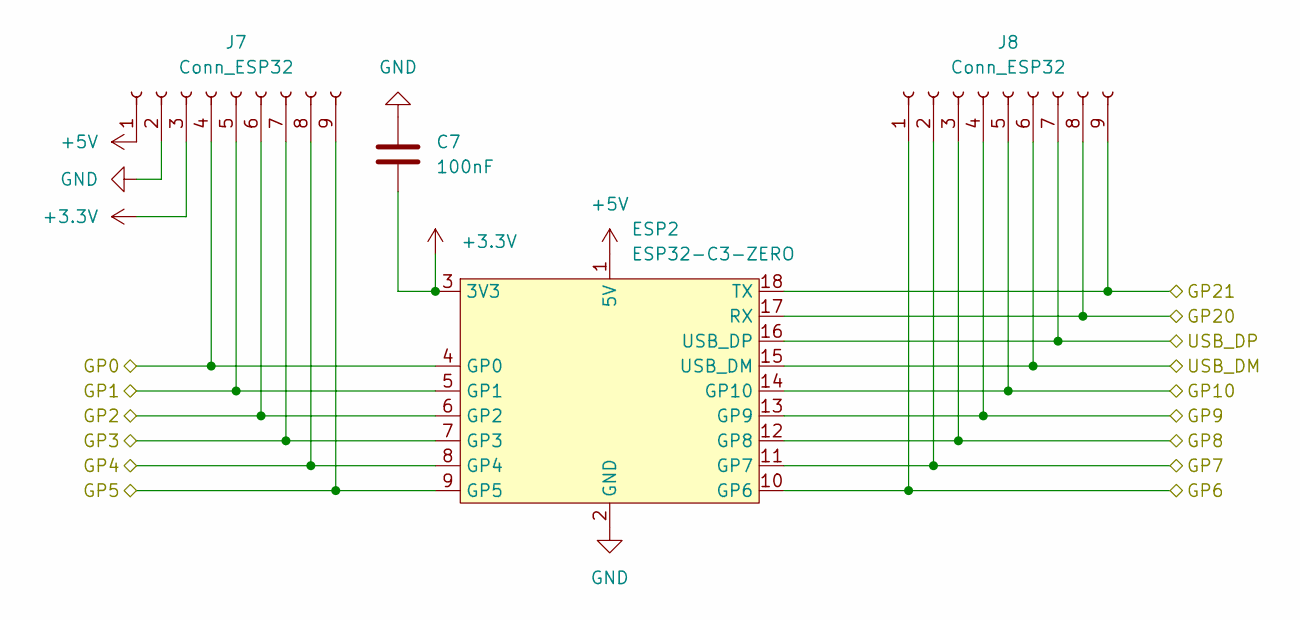
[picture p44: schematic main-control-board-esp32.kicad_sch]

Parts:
C7: 100nF; C_0603_1608Metric; MPN CC0603KRX7R9BB104; LCSC Part # C14663
ESP2: ESP32-C3-ZERO; ESP32_C3_Zero_Dev_Board
J7, J8: Conn_ESP32; PinSocket_1x09_P2.54mm_Vertical; MPN PM254-1-09-Z-8.5; LCSC Part # C2897372

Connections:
+3.3V: C7.1, ESP2.3 (3V3), J7.3; also elsewhere on the board
+5V: ESP2.1 (5V), J7.1; also elsewhere on the board
/ESP32/GP5: ESP2.9 (GP5), J7.9; also elsewhere on the board
/ESP32/GP6: ESP2.10 (GP6), J8.1; also elsewhere on the board
/ESP32/GP7: ESP2.11 (GP7), J8.2; also elsewhere on the board
/ESP32/GP8: ESP2.12 (GP8), J8.3; also elsewhere on the board
/ESP32/GP9: ESP2.13 (GP9), J8.4; also elsewhere on the board
/ESP32/GP10: ESP2.14 (GP10), J8.5
/ESP32/GP20: ESP2.17 (RX), J8.8; also elsewhere on the board
/ESP32/GP21: ESP2.18 (TX), J8.9; also elsewhere on the board
/I2C_SCL: ESP2.5 (GP1), J7.5; also elsewhere on the board
/I2C_SDA: ESP2.4 (GP0), J7.4; also elsewhere on the board
/I2S_BCLK: ESP2.6 (GP2), J7.6; also elsewhere on the board
/I2S_DIN: ESP2.8 (GP4), J7.8; also elsewhere on the board
/I2S_LRC: ESP2.7 (GP3), J7.7; also elsewhere on the board
/USB_D+: ESP2.16 (USB_DP), J8.7; also elsewhere on the board
/USB_D-: ESP2.15 (USB_DM), J8.6; also elsewhere on the board
GND: C7.2, ESP2.2 (GND), J7.2; also elsewhere on the board

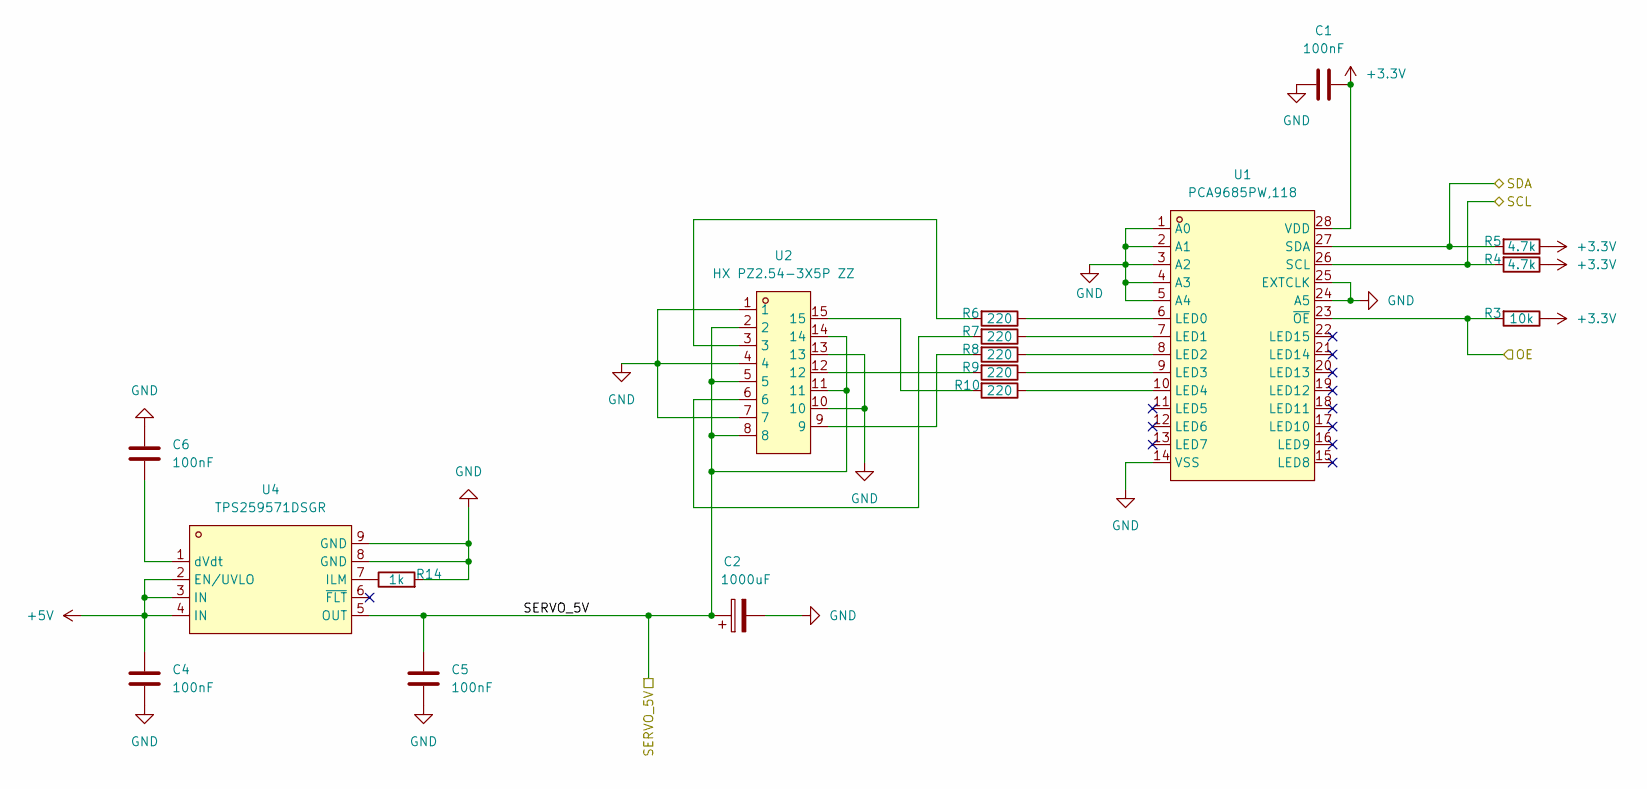
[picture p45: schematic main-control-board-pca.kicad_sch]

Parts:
C1, C4, C5, C6: 100nF; C_0603_1608Metric; MPN CC0603KRX7R9BB104; LCSC Part # C14663
C2: 1000uF; CP_Elec_10x10.5; MPN JVJ16V1000M10x10; LCSC Part # C46550395
R3: 10k; R_0603_1608Metric; MPN 0603WAF1002T5E; LCSC Part # C25804
R4, R5: 4.7k; R_0603_1608Metric; MPN 0603WAF4701T5E; LCSC Part # C23162
R6, R7, R8, R9, R10: 220; R_0603_1608Metric; MPN 0603WAF2200T5E; LCSC Part # C22962
R14: 1k; R_0603_1608Metric; MPN 0603WAF1001T5E; LCSC Part # C21190
U1: PCA9685PW,118; TSSOP-28_L9.7-W4.4-P0.65-LS6.4-TL; MPN PCA9685PW,118; LCSC Part # C2678753
U2: HX PZ2.54-3X5P ZZ; HDR-TH_15P-P2.54-V-M-R3-C5-S7.5; MPN HX PZ2.54-3x5P ZZ; LCSC Part # C32713292
U4: TPS259571DSGR; WSON-8_L2.0-W2.0-P0.50-TL-EP; MPN TPS259571DSGR; LCSC Part # C471038

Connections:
+3.3V: C1.2, R3.1, R4.1, R5.1, U1.28 (VDD); also elsewhere on the board
+5V: C4.2, U4.2 (EN/UVLO), U4.3 (IN), U4.4 (IN); also elsewhere on the board
/ESP32/GP5: R3.2, U1.23 (~OE); also elsewhere on the board
/I2C_SCL: R4.2, U1.26 (SCL); also elsewhere on the board
/I2C_SDA: R5.2, U1.27 (SDA); also elsewhere on the board
/PCA/SERVO_5V: C2.1, C5.2, U2.2, U2.5, U2.8, U2.11, U2.14, U4.5 (OUT); also elsewhere on the board
GND: C1.1, C2.2, C4.1, C5.1, C6.2, R14.2, U1.1 (A0), U1.2 (A1), U1.3 (A2), U1.4 (A3), U1.5 (A4), U1.14 (VSS), U1.24 (A5), U1.25 (EXTCLK), U2.1, U2.4, U2.7, U2.10, U2.13, U4.8 (GND), U4.9 (GND); also elsewhere on the board
unnamed: R6.2, U2.3
unnamed: R7.2, U2.6
unnamed: R8.2, U2.9
unnamed: R9.2, U2.12
unnamed: R10.2, U2.15
unnamed: R6.1, U1.6 (LED0)
unnamed: R7.1, U1.7 (LED1)
unnamed: R8.1, U1.8 (LED2)
unnamed: R9.1, U1.9 (LED3)
unnamed: R10.1, U1.10 (LED4)
unnamed: R14.1, U4.7 (ILM)
unnamed: C6.1, U4.1 (dVdt)

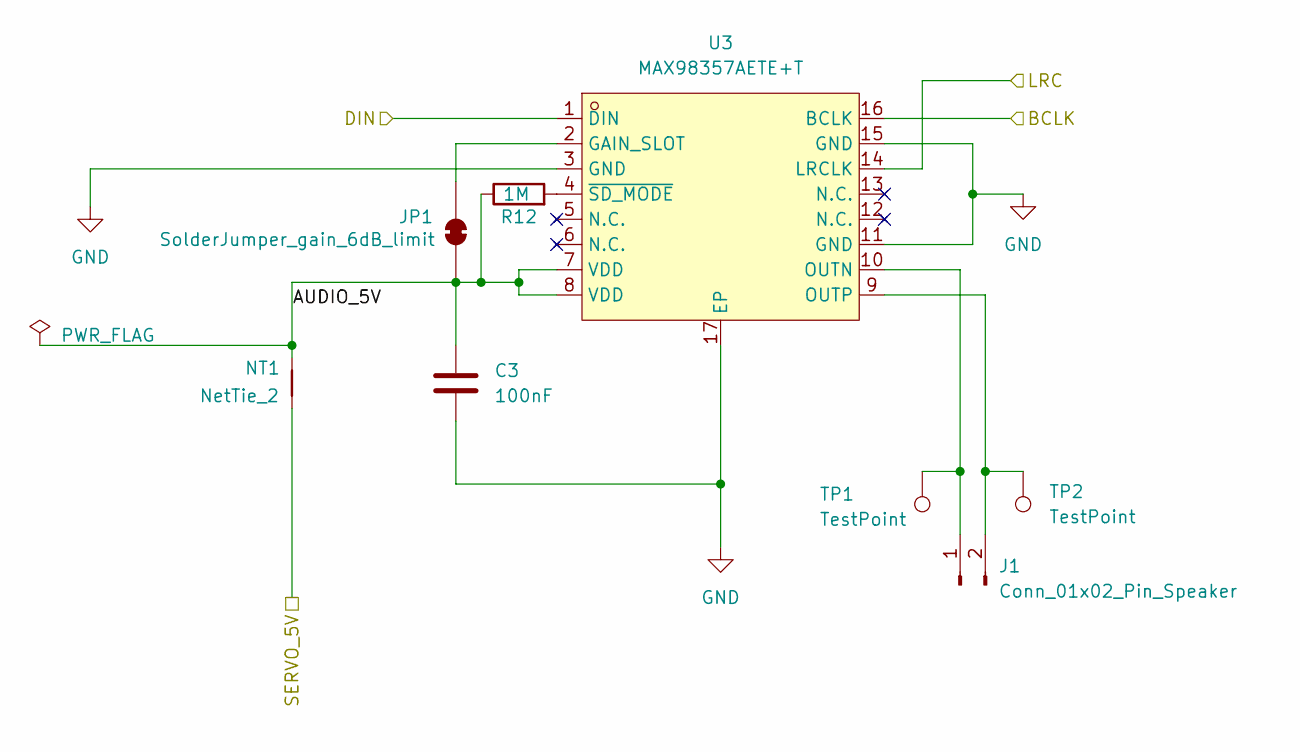
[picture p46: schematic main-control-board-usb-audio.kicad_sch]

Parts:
C3: 100nF; C_0603_1608Metric; LCSC Part # C14663
J1: Conn_01x02_Pin_Speaker; Molex_PicoBlade_53261-0271_1x02-1MP_P1.25mm_Horizontal; LCSC Part # C2845379
JP1: SolderJumper_gain_6dB_limit; SolderJumper-2_P1.3mm_Bridged_RoundedPad1.0x1.5mm
NT1: NetTie_2; NetTie-2_SMD_Pad2.0mm
R12: 1M; R_0603_1608Metric; LCSC Part # C22935
TP1, TP2: TestPoint; SolderWire-0.25sqmm_1x01_D0.65mm_OD2mm
U3: MAX98357AETE+T; TQFN-16_L3.0-W3.0-P0.50-BL-EP1.5; MPN MAX98357AETE+T; LCSC Part # C910544

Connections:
/Audio/AUDIO_5V: C3.2, JP1.1 (A), NT1.2, R12.1, U3.7 (VDD), U3.8 (VDD)
/I2S_BCLK: U3.16 (BCLK); also elsewhere on the board
/I2S_DIN: U3.1 (DIN); also elsewhere on the board
/I2S_LRC: U3.14 (LRCLK); also elsewhere on the board
/PCA/SERVO_5V: NT1.1; also elsewhere on the board
GND: C3.1, U3.3 (GND), U3.11 (GND), U3.15 (GND), U3.17 (EP); also elsewhere on the board
unnamed: J1.1, TP1.1 (1_1), U3.10 (OUTN)
unnamed: J1.2, TP2.1 (1_1), U3.9 (OUTP)
unnamed: JP1.2 (B), U3.2 (GAIN_SLOT)
unnamed: R12.2, U3.4 (~SD_MODE)

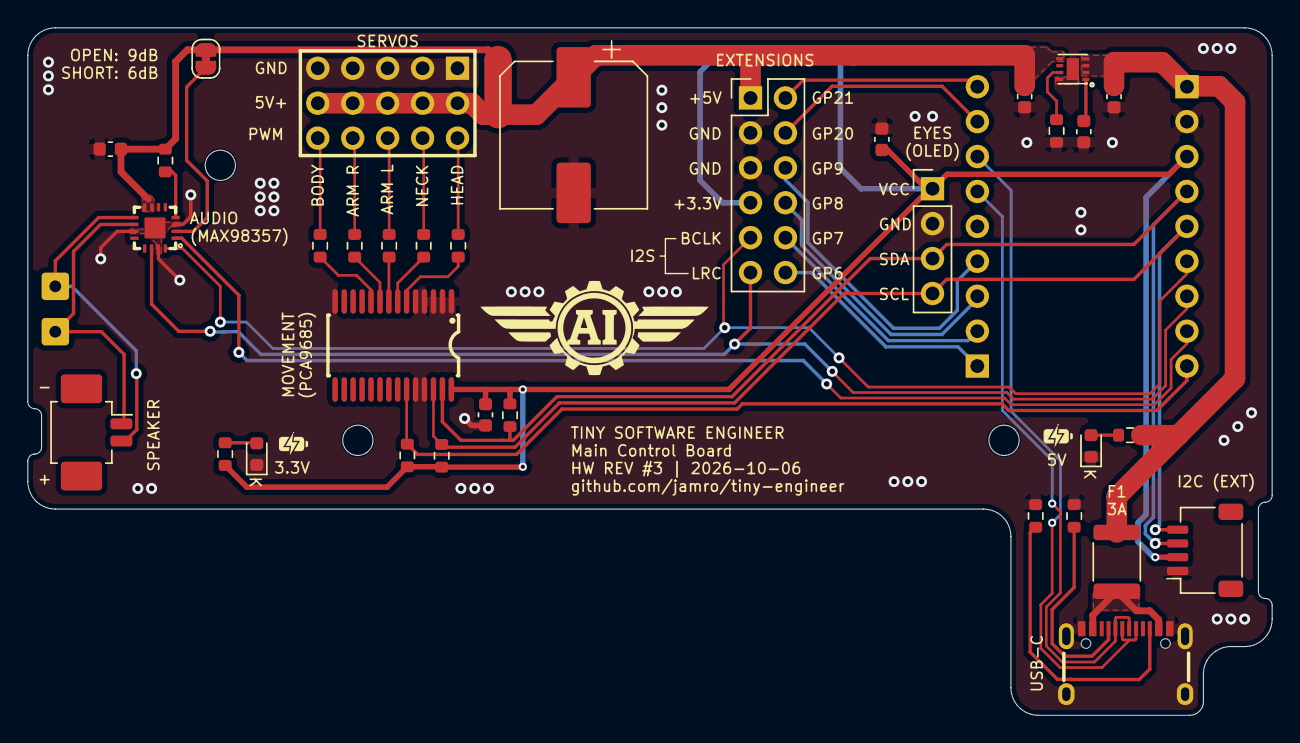
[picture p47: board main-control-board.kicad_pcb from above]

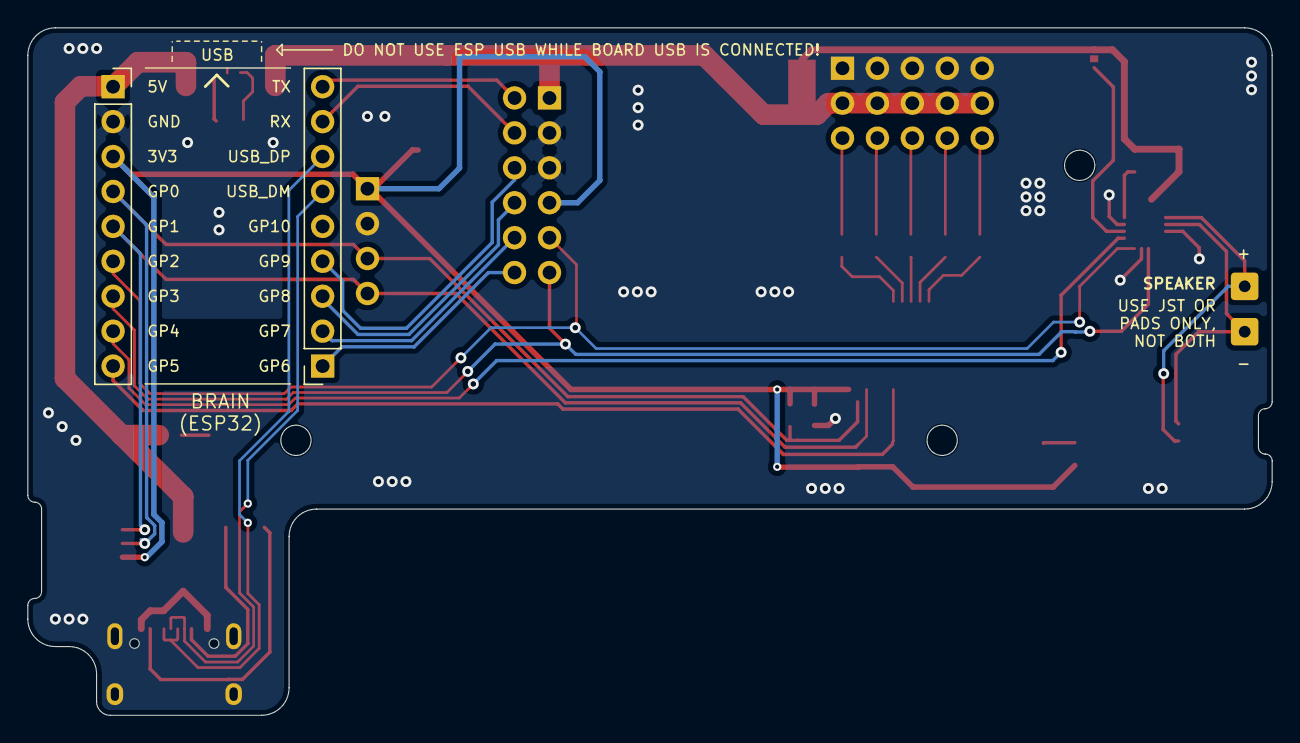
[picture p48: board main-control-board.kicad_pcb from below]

Board: 2 copper layers, 90.5 x 50.0 mm, 42 parts (2 on the bottom side), 40 nets.

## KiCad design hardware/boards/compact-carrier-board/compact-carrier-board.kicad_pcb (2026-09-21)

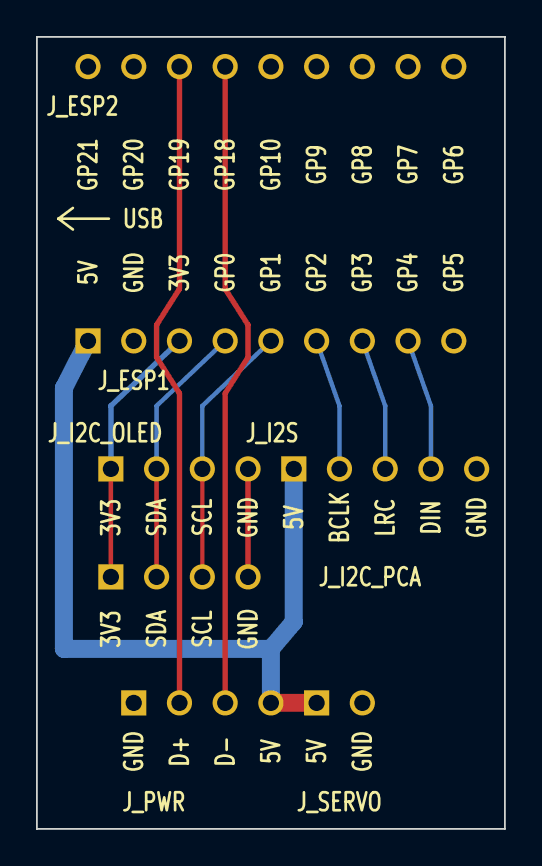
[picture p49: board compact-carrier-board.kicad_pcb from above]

Board: 2 copper layers, 26.0 x 44.0 mm, 7 parts (0 on the bottom side), 10 nets.

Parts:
J_ESP1: Kinghelm KH-2.54FH-1X9P-H3.5; J_ESP1
J_ESP2: Kinghelm KH-2.54FH-1X9P-H3.5; J_ESP2
J_I2C_OLED: J_I2C_OLED
J_I2C_PCA: J_I2C_PCA
J_I2S: J_I2S
J_PWR: J_PWR
J_SERVO: J_SERVO

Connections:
3V3: J_ESP1.3, J_I2C_OLED.1, J_I2C_PCA.1
5V: J_ESP1.1, J_I2S.1, J_PWR.4, J_SERVO.1
BCLK: J_ESP1.6, J_I2S.2
DIN: J_ESP1.8, J_I2S.4
GND: J_ESP1.2, J_I2C_OLED.4, J_I2C_PCA.4, J_I2S.5, J_PWR.1, J_SERVO.2
LRCLK: J_ESP1.7, J_I2S.3
SCL: J_ESP1.5, J_I2C_OLED.3, J_I2C_PCA.3
SDA: J_ESP1.4, J_I2C_OLED.2, J_I2C_PCA.2
USB_DM: J_ESP2.15, J_PWR.3
USB_DP: J_ESP2.16, J_PWR.2

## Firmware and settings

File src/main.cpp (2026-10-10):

#include <Arduino.h>
#include <Wire.h>
#include <ESP_I2S.h>

#include "pins.h"
#include "firmware_version.h"
#include "hardware/rgb.h"
#include "hardware/chip_temp.h"
#include "display/oled.h"
#include "audio/audio.h"
#include "animation.h"
#include "animation/constants.h"
#include "animation/util.h"
#include "hardware/pca9685_servos.h"
#include "hardware/servo_wrapper.h"
#include "network/wifi_connect.h"
#include "network/ota.h"
#include "http/http_server.h"
#include "settings/settings.h"
#include "serial_log.h"
#include "sleep.h"
#include "robot_tick.h"
#include "boot/boot_loading.h"

namespace {

constexpr int kBootSteps = 6;

}  // namespace

void setup() {
  initServoOutputPin();

  Serial.begin(115200);
  Serial.setTxTimeoutMs(0);
  delay(1000);

  initSettings();

  initChipTemp();

  serialLogPrintln();
  serialLogPrintln("==========================");
  serialLogPrintln("TINY ENGINEER");
  serialLogPrintln(FW_VERSION);
  serialLogPrintln("==========================");

  setRgb(0, 32, 0);

  serialLogPrintln();
  serialLogPrintln("Starting I2C");
  serialLogPrintln("SDA = GP0");
  serialLogPrintln("SCL = GP1");

  Wire.begin(
    I2C_SDA,
    I2C_SCL
  );

  delay(100);

  initPca9685();

  initOled();

  const bool sleepServos = bootSleepInertiaUsesServos();

  if (bootLoadingIsProgress()) {
    bootShowProgress(1, kBootSteps, "Display");
  } else {
    bootBeginSleepingFace();
  }

  if (sleepServos) {
    bootSnapSleepPose();
  }

  bootShowProgress(2, kBootSteps, "WiFi...");
  runWifiSetup();
  bootShowProgress(
    2,
    kBootSteps,
    wifiConnected() ? "WiFi OK" :
    wifiProvisioningMode() ? "WiFi setup" : "WiFi failed"
  );

  bootShowProgress(3, kBootSteps, "Servos");

  serialLogPrintln();
  serialLogPrintln(
    "Starting MAX98357A"
  );

  I2S.setPins(
    I2S_BCLK,
    I2S_LRC,
    I2S_DIN
  );

  if (!I2S.begin(
        I2S_MODE_STD,
        SAMPLE_RATE,
        I2S_DATA_BIT_WIDTH_16BIT,
        I2S_SLOT_MODE_STEREO
      )) {
    serialLogPrintln(
      "ERROR: I2S initialization failed"
    );

    showOledText(
      "I2S ERROR",
      "Init failed"
    );

    haltWithRgbCode(RGB_CODE_I2S);
  }

  serialLogPrintln("I2S OK");
  bootShowProgress(4, kBootSteps, "Audio");

  initAudioStorage();
  bootShowProgress(5, kBootSteps, "Storage");

  if (!sleepServos) {
    serialLogPrintln("Centering servos");
    centerAllServos();
  }

  if (bootLoadingIsProgress()) {
    bootShowProgress(kBootSteps, kBootSteps, "Ready");
    if (wifiProvisioningMode()) {
      showProvisioningOled("Join this WiFi", wifiApSsid());
    } else {
      showBootIp(wifiConnected() ? wifiIpText() : "");
      delay(3000);
      showIdleScreen();
    }
  } else {
    bootRunSleepInertia();
    if (wifiProvisioningMode()) {
      showProvisioningOled("Join this WiFi", wifiApSsid());
    }
  }

  serialLogPrintln();
  serialLogPrintln("==========================");
  serialLogPrintln("ROBOT READY");
  serialLogPrintln("==========================");

  if (wifiConnected() && settingsWelcomeEnabled()) {
    setAnimation(AnimationId::Welcome);
  } else if (wifiConnected() && !settingsWelcomeEnabled()) {
    anim::parkHands(anim::TRANSITION_HAND_SPEED_DEG_S);
    setRgbForAnimation(AnimationId::None, millis());
  } else if (wifiProvisioningMode()) {
    setRgb(0, 0, 64);
  } else {
    setRgbForAnimation(AnimationId::None, millis());
  }

  if (wifiConnected() || wifiProvisioningMode()) {
    startHttpServer();
  }

  if (wifiConnected()) {
    startOta();
  }
  initSleep();
}

void loop() {
  pollHttpServer();
  pollOta();
  tickRobot();
}

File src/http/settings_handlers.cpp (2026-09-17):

#include "http/settings_handlers.h"

#include <Arduino.h>
#include <cstdlib>
#include <cstdio>
#include <cstring>

#include "display/oled.h"
#include "http/json.h"
#include "http/server_context.h"
#include "network/wifi_connect.h"
#include "settings/settings.h"

namespace {

void formatServoRangeJson(char* dest, size_t destSize) {
  snprintf(
    dest,
    destSize,
    "\"servo_mins\":[%u,%u,%u,%u,%u],"
    "\"servo_maxs\":[%u,%u,%u,%u,%u],"
    "\"rgb_order\":\"%s\","
    "\"oled_rotate_180\":%s",
    static_cast<unsigned>(settingsServoMin(0)),
    static_cast<unsigned>(settingsServoMin(1)),
    static_cast<unsigned>(settingsServoMin(2)),
    static_cast<unsigned>(settingsServoMin(3)),
    static_cast<unsigned>(settingsServoMin(4)),
    static_cast<unsigned>(settingsServoMax(0)),
    static_cast<unsigned>(settingsServoMax(1)),
    static_cast<unsigned>(settingsServoMax(2)),
    static_cast<unsigned>(settingsServoMax(3)),
    static_cast<unsigned>(settingsServoMax(4)),
    settingsRgbOrder(),
    settingsOledRotate180() ? "true" : "false"
  );
}

bool parseServoCsv(const String& raw, uint8_t out[SETTINGS_SERVO_COUNT]) {
  const char* p = raw.c_str();

  for (size_t i = 0; i < SETTINGS_SERVO_COUNT; i++) {
    if (p == nullptr || *p == '\0') {
      return false;
    }

    char* end = nullptr;
    const unsigned long parsed = strtoul(p, &end, 10);

    if (end == p || parsed > 255) {
      return false;
    }

    if (i + 1 < SETTINGS_SERVO_COUNT) {
      if (*end != ',') {
        return false;
      }

      p = end + 1;
    } else if (*end != '\0') {
      return false;
    }

    out[i] = static_cast<uint8_t>(parsed);
  }

  return true;
}

void sendSettingsJson(
  WebServer& server,
  bool rebootRequired,
  bool wifiConnectSuccess
) {
  char servoJson[176];
  formatServoRangeJson(servoJson, sizeof(servoJson));
  char body[1100];
  const char* tokenSet =
    settingsAccessTokenSet() ? "true" : "false";
  const char* wifiConfigured =
    settingsWifiConfigured() ? "true" : "false";
  const char* wifiPasswordSet =
    settingsWifiPasswordSet() ? "true" : "false";

  if (wifiConnectSuccess) {
    snprintf(
      body,
      sizeof(body),
      "{"
      "\"ok\":true,"
      "\"sleep_timeout\":%lu,"
      "\"hostname\":\"%s\","
      "\"volume\":%u,"
      "\"welcome\":%s,"
      "\"serial_log\":%s,"
      "\"continuous_timeout\":%lu,"
      "\"loading\":\"%s\","
      "\"eyes_style\":\"%s\","
      "\"access_token_set\":%s,"
      "\"wifi_configured\":%s,"
      "\"wifi_ssid\":\"%s\","
      "\"wifi_password_set\":%s,"
      "%s,"
      "\"wifi_connect_success\":true,"
      "\"wifi_ip\":\"%s\","
      "\"wifi_hostname\":\"%s\""
      "%s"
      "}",
      (unsigned long)settingsSleepTimeoutMin(),
      settingsHostname(),
      static_cast<unsigned>(settingsVolume()),
      settingsWelcomeEnabled() ? "true" : "false",
      settingsSerialLogEnabled() ? "true" : "false",
      (unsigned long)settingsContinuousTimeoutMin(),
      settingsLoading(),
      settingsEyesStyle(),
      tokenSet,
      wifiConfigured,
      settingsWifiSsid(),
      wifiPasswordSet,
      servoJson,
      wifiIpText(),
      httpMdnsHostname(),
      rebootRequired ? ",\"reboot_required\":true" : ""
    );
  } else if (rebootRequired) {
    snprintf(
      body,
      sizeof(body),
      "{"
      "\"ok\":true,"
      "\"sleep_timeout\":%lu,"
      "\"hostname\":\"%s\","
      "\"volume\":%u,"
      "\"welcome\":%s,"
      "\"serial_log\":%s,"
      "\"continuous_timeout\":%lu,"
      "\"loading\":\"%s\","
      "\"eyes_style\":\"%s\","
      "\"access_token_set\":%s,"
      "\"wifi_configured\":%s,"
      "\"wifi_ssid\":\"%s\","
      "\"wifi_password_set\":%s,"
      "%s,"
      "\"reboot_required\":true"
      "}",
      (unsigned long)settingsSleepTimeoutMin(),
      settingsHostname(),
      static_cast<unsigned>(settingsVolume()),
      settingsWelcomeEnabled() ? "true" : "false",
      settingsSerialLogEnabled() ? "true" : "false",
      (unsigned long)settingsContinuousTimeoutMin(),
      settingsLoading(),
      settingsEyesStyle(),
      tokenSet,
      wifiConfigured,
      settingsWifiSsid(),
      wifiPasswordSet,
      servoJson
    );
  } else {
    snprintf(
      body,
      sizeof(body),
      "{"
      "\"ok\":true,"
      "\"sleep_timeout\":%lu,"
      "\"hostname\":\"%s\","
      "\"volume\":%u,"
      "\"welcome\":%s,"
      "\"serial_log\":%s,"
      "\"continuous_timeout\":%lu,"
      "\"loading\":\"%s\","
      "\"eyes_style\":\"%s\","
      "\"access_token_set\":%s,"
      "\"wifi_configured\":%s,"
      "\"wifi_ssid\":\"%s\","
      "\"wifi_password_set\":%s,"
      "%s"
      "}",
      (unsigned long)settingsSleepTimeoutMin(),
      settingsHostname(),
      static_cast<unsigned>(settingsVolume()),
      settingsWelcomeEnabled() ? "true" : "false",
      settingsSerialLogEnabled() ? "true" : "false",
      (unsigned long)settingsContinuousTimeoutMin(),
      settingsLoading(),
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

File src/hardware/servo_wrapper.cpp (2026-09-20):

#include <Arduino.h>
#include <Adafruit_PWMServoDriver.h>

#include "animation/util.h"
#include "pins.h"
#include "servos.h"
#include "hardware/servo_wrapper.h"
#include "serial_log.h"
#include "settings/settings.h"

Adafruit_PWMServoDriver pwm(PCA9685_ADDRESS);

// PCA9685 LEDn_OFF full-off bit. Do not use (4096, 0) — that is full-on HIGH.
constexpr uint16_t kPca9685FullOff = 4096;
static bool g_allOutputsReleased = false;

ServoWrapper g_servos[SERVO_COUNT] = {
  ServoWrapper(SERVO_HEAD),
  ServoWrapper(SERVO_NECK),
  ServoWrapper(SERVO_HAND_LEFT),
  ServoWrapper(SERVO_HAND_RIGHT),
  ServoWrapper(SERVO_BODY)
};

uint16_t angleToPulse(float angle) {
  angle = constrain(angle, 0.0f, 180.0f);

  const float pulseUs =
    SERVO_MIN_US +
    (angle / 180.0f) *
    (SERVO_MAX_US - SERVO_MIN_US);

  const float counts =
    pulseUs * 4096.0f / 20000.0f + 0.5f;

  return (uint16_t)constrain(counts, 0.0f, 4095.0f);
}

float clampElectricalAngle(float angle) {
  return constrain(angle, 0.0f, 180.0f);
}

float clampServoAngle(int index, float angle) {
  if (index < 0 || index >= SERVO_COUNT) {
    return clampElectricalAngle(angle);
  }

  return constrain(
    angle,
    settingsServoMin(index),
    settingsServoMax(index)
  );
}

float clampAngle(int index, float angle, bool electrical) {
  if (electrical) {
    return clampElectricalAngle(angle);
  }

  return clampServoAngle(index, angle);
}

float servoRuntimeMid(int index) {
  return servoNormToDeg(index, 0.0f);
}

float servoNormToDeg(int index, float n) {
  if (index < 0 || index >= SERVO_COUNT) {
    return servoNormToDeg(n, 0.0f, 180.0f);
  }

  return servoNormToDeg(
    n,
    settingsServoMin(index),
    settingsServoMax(index)
  );
}

float servoDegToNorm(int index, float deg) {
  if (index < 0 || index >= SERVO_COUNT) {
    return servoDegToNorm(deg, 0.0f, 180.0f);
  }

  return servoDegToNorm(
    deg,
    settingsServoMin(index),
    settingsServoMax(index)
  );
}

void initServoOutputPin() {
  if (!PCA9685_OE_WIRED) {
    return;
  }

  pinMode(PCA9685_OE_PIN, OUTPUT);
  digitalWrite(PCA9685_OE_PIN, HIGH);
}

void disableServoOutputs() {
  if (!PCA9685_OE_WIRED) {
    return;
  }

  digitalWrite(PCA9685_OE_PIN, HIGH);
}

void enableServoOutputs() {
  if (!PCA9685_OE_WIRED) {
    return;
  }

  digitalWrite(PCA9685_OE_PIN, LOW);
}

void initServoPwmDriver() {
  disableServoOutputs();

  pwm.begin();
  pwm.setPWMFreq(50);
  delay(100);

  for (int i = 0; i < SERVO_COUNT; i++) {
    g_servos[i].setPosition(servoRuntimeMid(i));
  }

  delay(10);
  enableServoOutputs();
}

ServoWrapper& servoAt(int index) {
  return g_servos[index];
}

ServoWrapper::ServoWrapper(int index)
  : index_(index),
    angle_(servoMid(SERVO_SPECS[index])),
    target_(angle_),
    speedDegS_(SERVO_MAX_SPEED_DEG_S),
    lastUpdateMs_(0),
    lastPulse_(UINT16_MAX),
    released_(false) {}

float ServoWrapper::angle() const {
  return angle_;
}

void ServoWrapper::setTarget(float target, float speedDegS) {
  ensureServoOutput();
  target_ = clampServoAngle(index_, target);
  speedDegS_ = constrain(
    speedDegS,
    0.0f,
    SERVO_MAX_SPEED_DEG_S
  );
}

void ServoWrapper::setPosition(float angle) {
  angle = clampServoAngle(index_, angle);
  writeAngle(angle, false, false);
  target_ = angle_;
  lastUpdateMs_ = 0;
}

void ServoWrapper::setNormTarget(float n, float speedDegS) {
  setTarget(servoNormToDeg(index_, n), speedDegS);
}

void ServoWrapper::setNormPosition(float n) {
  setPosition(servoNormToDeg(index_, n));
}

void ServoWrapper::stop() {
  target_ = angle_;
}

bool ServoWrapper::isMoving() const {
  return fabsf(target_ - angle_) >= SERVO_ANGLE_DEADBAND_DEG;
}

void ServoWrapper::update() {
  if (!isMoving()) {
    return;
  }

  const uint32_t now = millis();

  if (lastUpdateMs_ == 0) {
    lastUpdateMs_ = now;
    return;
  }

  const uint32_t elapsed = now - lastUpdateMs_;

  if (elapsed < (uint32_t)SERVO_STEP_MS) {
    return;
  }

  lastUpdateMs_ = now;

  const float maxStep =
    speedDegS_ * ((float)elapsed / 1000.0f);
  const float delta = target_ - angle_;
  const float step =
    constrain(delta, -maxStep, maxStep);
  const float next = angle_ + step;

  if (fabsf(target_ - next) < SERVO_ANGLE_DEADBAND_DEG) {
    writeAngle(target_, false, false);
    lastUpdateMs_ = 0;
    return;
  }

  writeAngle(next, false, false);
}

void updateAllServos() {
  for (int i = 0; i < SERVO_COUNT; i++) {
    g_servos[i].update();
  }
}

bool anyServoMoving() {
  for (int i = 0; i < SERVO_COUNT; i++) {
    if (g_servos[i].isMoving()) {
      return true;
    }
  }

  return false;
}

void ensureAllServoOutputs() {
  for (int i = 0; i < SERVO_COUNT; i++) {
    g_servos[i].ensureServoOutput();
  }
}

void releaseAllServoOutputs() {
  if (g_allOutputsReleased) {
    return;
  }

  for (int i = 0; i < SERVO_COUNT; i++) {
    g_servos[i].releaseServoOutput();
  }

  g_allOutputsReleased = true;
  serialLogPrintln("[servo] pwm off");
}

void ServoWrapper::ensureServoOutput() {
  if (!released_) {
    return;
  }

  released_ = false;
  g_allOutputsReleased = false;
  lastPulse_ = UINT16_MAX;

  const uint16_t pulse = angleToPulse(angle_);
  pwm.setPWM(
    SERVO_SPECS[index_].channel,
    0,
    pulse
  );
  lastPulse_ = pulse;

  serialLogPrint("[servo] pwm on ");
  serialLogPrint(SERVO_SPECS[index_].name);
  serialLogPrint(" ch=");
  serialLogPrintln(SERVO_SPECS[index_].channel);
}

void ServoWrapper::releaseServoOutput() {
  if (released_) {
    return;
  }

  pwm.setPWM(
    SERVO_SPECS[index_].channel,
    0,
    kPca9685FullOff
  );
  lastPulse_ = UINT16_MAX;
  released_ = true;
}

void ServoWrapper::writeAngle(float angle, bool log, bool electrical) {
  ensureServoOutput();
  angle = clampAngle(index_, angle, electrical);

  const uint16_t pulse = angleToPulse(angle);

  if (log) {
    serialLogPrint("Servo ");
    serialLogPrint(SERVO_SPECS[index_].name);
    serialLogPrint(" -> ");
    serialLogPrint(angle);
    serialLogPrint(" deg, pulse: ");
    serialLogPrintln(pulse);
  }

  if (pulse != lastPulse_) {
    pwm.setPWM(
      SERVO_SPECS[index_].channel,
      0,
      pulse
    );
    lastPulse_ = pulse;
  }

  angle_ = angle;
}

void ServoWrapper::snapTo(float angle) {
  writeAngle(angle, true, false);
  target_ = angle_;
  lastUpdateMs_ = 0;
}
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

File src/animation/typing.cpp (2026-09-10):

#include <Arduino.h>

#include "animation.h"
#include "animation/constants.h"
#include "animation/typing.h"
#include "animation/util.h"
#include "hardware/servo_wrapper.h"
#include "servos.h"
#include "serial_log.h"

using anim::parkTorso;
using anim::randChance;
using anim::randRangeMs;
using anim::randUnit;
using anim::snapHeadToRangeHigh;
using anim::stopAnimServos;

namespace {

bool g_typingMoveRight = true;
bool g_rightIsPress = true;
bool g_leftIsPress = true;
bool g_lastStrokeWasPress = false;
bool g_headHigh = true;
bool g_bodySwayPositive = true;
bool g_swayFrozen = false;
bool g_loggedSwaySplit = false;
uint32_t g_handPauseUntilMs = 0;
uint32_t g_headPauseUntilMs = 0;
uint32_t g_swayPauseUntilMs = 0;

void commandBodyNeckSway() {
  const float offset =
    g_bodySwayPositive ? anim::TYPING_SWAY : -anim::TYPING_SWAY;
  const float speedDegS =
    12.0f + 18.0f * randUnit();

  servoAt(SERVO_BODY).setNormTarget(
    anim::TYPING_BODY_MID + offset,
    speedDegS
  );
  servoAt(SERVO_NECK).setNormTarget(
    anim::TYPING_NECK_MID - offset,
    speedDegS
  );

  serialLogPrint("[anim] typing sway body->");
  serialLogPrint(servoNormToDeg(SERVO_BODY, anim::TYPING_BODY_MID + offset), 1);
  serialLogPrint(" neck->");
  serialLogPrint(servoNormToDeg(SERVO_NECK, anim::TYPING_NECK_MID - offset), 1);
  serialLogPrint(" speed=");
  serialLogPrint(speedDegS, 1);
  serialLogPrint(" dir=");
  serialLogPrintln(g_bodySwayPositive ? "right" : "left");
}

void commandHandStroke() {
  if (!randChance(45)) {
    g_typingMoveRight = !g_typingMoveRight;
  }

  const bool isPress = g_typingMoveRight ? g_rightIsPress : g_leftIsPress;
  g_lastStrokeWasPress = isPress;

  if (g_typingMoveRight) {
    g_rightIsPress = !g_rightIsPress;
  } else {
    g_leftIsPress = !g_leftIsPress;
  }

  const float lift = 0.55f + 0.45f * randUnit();
  const float speedDegS = isPress
    ? SERVO_MAX_SPEED_DEG_S * (0.55f + 0.20f * randUnit())
    : SERVO_MAX_SPEED_DEG_S * (0.85f + 0.15f * randUnit());

  if (g_typingMoveRight) {
    const float target = isPress
      ? anim::TYPING_RIGHT_LOW
      : anim::TYPING_RIGHT_LOW + lift * anim::TYPING_HAND_BAND;
    servoAt(SERVO_HAND_RIGHT).setNormTarget(target, speedDegS);
  } else {
    const float target = isPress
      ? anim::TYPING_LEFT_HIGH
      : anim::TYPING_LEFT_HIGH - lift * anim::TYPING_HAND_BAND;
    servoAt(SERVO_HAND_LEFT).setNormTarget(target, speedDegS);
  }
}

void commandHead() {
  if (g_headHigh) {
    const float upSpeed =
      35.0f + 25.0f * randUnit();
    servoAt(SERVO_HEAD).setNormTarget(
      anim::TYPING_HEAD_HIGH,
      upSpeed
    );
  } else {
    const float downSpeed =
      6.0f + 6.0f * randUnit();
    servoAt(SERVO_HEAD).setNormTarget(
      anim::TYPING_HEAD_LOW,
      downSpeed
    );
  }
}

void advanceTypingStep() {
  const uint32_t pauseMs = g_lastStrokeWasPress
    ? randRangeMs(15, 40)
    : (randChance(8) ? randRangeMs(40, 90) : randRangeMs(0, 25));
  g_handPauseUntilMs = millis() + pauseMs;
}

void beginNextHandStroke() {
  g_handPauseUntilMs = 0;
  commandHandStroke();
}

void advanceHeadStep() {
  g_headHigh = !g_headHigh;

  if (g_headHigh) {
    g_headPauseUntilMs = millis() + randRangeMs(80, 220);
  } else {
    g_headPauseUntilMs = millis() + randRangeMs(120, 350);
  }
}

void beginNextHeadMove() {
  g_headPauseUntilMs = 0;
  commandHead();
}

void advanceSwayStep() {
  g_bodySwayPositive = !g_bodySwayPositive;
  const uint32_t pauseMs = randRangeMs(40, 160);
  g_swayPauseUntilMs = millis() + pauseMs;
  g_loggedSwaySplit = false;

  serialLogPrint("[anim] typing sway done body=");
  serialLogPrint(servoAt(SERVO_BODY).angle(), 1);
  serialLogPrint(" neck=");
  serialLogPrint(servoAt(SERVO_NECK).angle(), 1);
  serialLogPrint(" pauseMs=");
  serialLogPrintln(pauseMs);
}

void beginNextSway() {
  g_swayPauseUntilMs = 0;
  g_loggedSwaySplit = false;
  commandBodyNeckSway();
}

}  // namespace

void startTyping() {
  stopAnimServos();
  g_typingMoveRight = randChance(50);
  g_rightIsPress = true;
  g_leftIsPress = true;
  g_lastStrokeWasPress = false;
  g_bodySwayPositive = randChance(50);
  g_swayFrozen = false;
  g_loggedSwaySplit = false;
  g_handPauseUntilMs = 0;
  g_swayPauseUntilMs = 0;
  g_headHigh = true;
  g_headPauseUntilMs = 0;
  commandBodyNeckSway();
  commandHandStroke();
  snapHeadToRangeHigh(anim::TYPING_HEAD_HIGH);
}
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

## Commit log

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2026-08-22 add bell sound
    [partitions.csv]
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2026-08-22 fix animatino shake glitch
    [attention.cpp, audio.cpp, constants.h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]
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2026-08-23 add factory reset
    [partitions.csv]
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2026-08-26 add 3d models
    [AiEmblem.3mf, Arm.3mf, Bell.3mf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]
2026-08-28 add missing hat part
    [Hat.3mf]
2026-08-30 fix #2: adding link to speaker in BOM
2026-09-01 fix: add missing screw hole to desk pad model #14
    [DeskPad.3mf, TinyEngineer.f3d]
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2026-09-07 fix(scripts): keep $PROJECT_DIR intact when it contains a space (#20)
    SCons tokenizes a command string on whitespace after substituting into it,
    so `-d $PROJECT_DIR` reached PlatformIO truncated at the first space and both
    the buildfs and uploadfs steps failed with:
    Error: Invalid value for '-d' / '--project-dir':
    Path 'E:\Users\Jon\Downloads\Tiny' does not exist.
    Quoting inside the string does not help (SCons keeps the quote characters
    attached to the split tokens, putting a stray `"` inside the path), and
    neither does passing a list to env.Execute (each element is re-tokenized
    after substitution). Build the argument vector in Python and spawn it with
    subprocess instead, so nothin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
2026-09-08 docs: give the serial port per platform, not just the macOS form (#21)
    The multi-port snippet in getting-started.md showed only
    `/dev/cu.usbserial-XXXX`. On Windows that gets copied verbatim, `XXXX` and
    all, and esptool fails with a path error that reads like a driver or cable
    problem rather than a wrong port name:
    A fatal error occurred: Could not open /dev/cu.usbserial-XXXX:,
    the port is busy or doesn't exist.
    Use a `<PORT>` placeholder and name the form for each platform. Also point
    at the VID:PID to pick by, since `pio device list` lists Bluetooth serial
    ports alongside the board and on Windows those sort first.
2026-09-08 feat(rgb): identify the failed subsystem with a red blink code (#23)
    Both fatal init failures halted with the same solid red, so the LED said
    "boot failed" but not where.
    That matters because the two halts sit before Wi-Fi: serial logging is off
    by default, a board with unwritten NVS falls back to that default, and the
    HTTP settings API that could turn logging on is unreachable behind the halt.
    Such a board stops, prints nothing about why, and cannot be told to start
    printing -- the LED is the only signal it gives.
    Route both halts through haltWithRgbCode(), which blinks red N times, pauses,
    and repeats. 1 = PCA9685 not found, 2 = I2S init failed, as named constants
    in rgb.h.
    The 3000 ms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
    [main.cpp, pca9685_servos.cpp]
2026-09-08 feat: add wizard to first time config with servo callibration
    * add wizard to first time config with servo callibration #25
    * feat: configure RGB LED mapping from config wizard #22
    * feat: add speaker test to init config wizard
    * fix: keep setup AP up until Connect JSON is sent
    STA test was turning the radio off and tearing down the AP before the
    phone got wifi_connect_success, so the wizard showed Network error and
    OLED stayed on Join AP.
    * refactor: split settings into src/settings/
    Break getters, validation, NVS, load, save, and reset into separate files so the old 555-line storage module is easier to follow.
    [partitions.csv]
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2026-09-10 feat(cad)!: parametric 3d model with support for FS0307 and SG90 (#27)
    feat!: add parametric multi-servo CAD support, parts export, OLED rotation setup, and calibrated servo poses
    * Add Fusion TinyEngineer add-in with servo configuration and 3MF/STL parts exporter
    * Redesign parametric 3D model with SG90 and HD-1370A support
    * Add servo_id handling and reorganize exported parts by servo type
    * Add OLED rotation configuration to setup wizard, settings, API, and docs
    * Normalize animation poses to -1..1 and map them through calibrated servo min/max
    * Update servo compatibility, wiring, printing, assembly, API, and hardware documentation
    BREAKING CHANGE: The 3D model was redesigned from scrat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
    [AiEmblem.3mf, AiEmblem.stl, Arm.3mf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]
2026-09-10 feat: enhance parts exporter to support STEP file generation
    - Updated the parts exporter to include STEP file export alongside existing 3MF and STL formats.
    - New STEP files created for various parts including and servos
    [AiEmblem.step, Bell.step, Belly.step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]
2026-09-12 fix: incorrect SG90 width in models #30
    [AiEmblem.3mf, AiEmblem.step, AiEmblem.stl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]
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2026-09-17 feat(cad): Add Screw Tolerance Test and update docs #29
    [ScrewSizingTest.3mf, ScrewSizingTest.step, ScrewSizingTest.stl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]
2026-09-18 feat(cad): Prepare models for external 3D printing with PCBWay #40
    - Revised the 3D printing section in README.md to clarify that users can either print parts themselves or order them from a provider.
    - Enhanced the 3D model (screw thread reduced from 2.2mm to 2.1mm)
    - Introduced new aggregated part sets (PartsSetA.3mf and PartsSetB.3mf) for easier ordering.
    - Updated all stl/3mf/step files
    [AiEmblem.3mf, AiEmblem.step, AiEmblem.stl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]
2026-09-18 fix(cad): add missing bell mount hole
    [AiEmblem.3mf, AiEmblem.step, AiEmblem.stl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]
2026-09-19 feat(cad): update 3D model for Neck to make assembly orientation easier
    Adding a bulge on one side of the neck component to facilitate correct orientation of the part during assembly
    [Neck.3mf, Neck.step, Neck.stl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]
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2026-09-19 fix(cad): Tighten the S90 servo mount #43
    [AiEmblem.3mf, AiEmblem.step, Bell.3mf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]
2026-09-20 fix(cad): Move lamp base opening to better align with ESP32 LED #42
    [LampBase.3mf, LampBase.step, LampBase.stl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]
2026-09-20 feat: enhance parts exporter functionality by input parmams
    - Added options to export selected PRINT_LAYOUT children in multiple formats (3MF, STL, STEP).
    - Introduced a command dialog for selecting servos and formats during export.
    - Improved error handling in servo parameter application to provide user feedback.
    - Updated documentation to reflect changes in export functionality and user interaction.
    [servo.py]
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2026-09-20 fix(firmware): start sleep-inertia OLED at wakeup t=0
    [boot_loading.cpp, wakeup.cpp]
2026-09-20 feat(anim): implement dead state with audio feedback and update related documentation
    - Added `dead.wav` audio playback for the out-of-power state, enhancing user experience.
    - Updated animation logic to handle the new dead state, including servo collapse behavior.
    - Modified documentation to reflect changes in the `dead` animation and its requirements.
    - Included `dead.wav` in asset management scripts and ensured proper integration in the animation controller.
    [partitions.csv]
2026-09-21 feat(pcb): add compact-carrier-board for ESP32-C3-Zero (#32)
    Adds a 26x44mm fabricatable carrier PCB sized to the real enclosure, routing power, I2C, I2S, servo, OLED, PCA9685, MAX98357A, and USB D+/D- fully on-board.
    ---------
    [compact-carrier-board.kicad_pcb]
2026-09-21 feat(pcb): add main-control-board MVP (#35)
    Adds a main control PCB with goldpin headers for stacking all components, reducing wiring and simplifying assembly.
    The board is too bulky for smalest servos, but works well with SG90-based setups. Includes KiCad design files, validation checks, documentation, and a JLCPCB BOM
    The PCB can be ordered either fully assembled or as a bare board for manual assembly.
    [main-control-board.kicad_pcb, main-control-board.kicad_sch]
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2026-10-04 reshape the board to mount SDM USB
    [main-control-board.kicad_pcb, main-control-board.kicad_sch]
2026-10-04 use hierarchical sheets in schmatic
    [main-control-board-esp32.kicad_sch, main-control-board-pca.kicad_sch, main-control-board-usb-audio.kicad_sch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]
2026-10-04 integrate PCA into the board
    [main-control-board-esp32.kicad_sch, main-control-board-pca.kicad_sch, main-control-board-usb.kicad_sch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]
2026-10-04 add power indicator
    [main-control-board-usb.kicad_sch, main-control-board.kicad_pcb]
2026-10-04 set FT Rotation Offset to fix JLCPCB orientation
    [main-control-board-esp32.kicad_sch, main-control-board-pca.kicad_sch, main-control-board.kicad_pcb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]
2026-10-04 integrate audio module
    [main-control-board-usb-audio.kicad_sch, main-control-board.kicad_pcb]
2026-10-04 improve board visuals
    [main-control-board-usb-audio.kicad_sch, main-control-board.kicad_pcb]
2026-10-04 add I2C extension port
    [main-control-board-usb-audio.kicad_sch, main-control-board.kicad_pcb, main-control-board.kicad_sch]
2026-10-04 use basic components over extended
    [main-control-board-pca.kicad_sch, main-control-board-usb-audio.kicad_sch, main-control-board-usb.kicad_sch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]
2026-10-04 add polyfuse protection
    [main-control-board-usb-audio.kicad_sch, main-control-board-usb.kicad_sch, main-control-board.kicad_pcb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]
2026-10-04 turn test points into extension points
    [main-control-board-esp32.kicad_sch, main-control-board.kicad_pcb, main-control-board.kicad_sch]
2026-10-04 pre-fab improvements
    [main-control-board-esp32.kicad_sch, main-control-board-pca.kicad_sch, main-control-board-usb-audio.kicad_sch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]
2026-10-04 fix expected nets
    [main-control-board.kicad_pcb, main-control-board.kicad_sch]
2026-10-04 fix check pcb
2026-10-04 update line coordinates in main control board PCB and footprint files for improved alignment
    [main-control-board.kicad_pcb]
2026-10-04 update line coordinates in TSSOP-28 footprint and main control board PCB for consistency and alignment
    [main-control-board.kicad_pcb]
2026-10-04 add efuse before 5V servo rail
    [main-control-board-pca.kicad_sch, main-control-board-usb-audio.kicad_sch, main-control-board.kicad_pcb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]
2026-10-04 clarify handling of lookup failures in JLCPCB BOM verification process
2026-10-04 fix(firmware): update PCA9685 output enable handling in documentation and code; set `PCA9685_OE_WIRED` to true, reflecting active LOW configuration for GP5
    [pins.h]
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2026-10-04 feat(cad): adjust desk model to be compatible with main control board
    [AiEmblem.3mf, AiEmblem.step, AiEmblem.stl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]
2026-10-04 fix(cad): fix gemotery of pcb holder in desk
    [Desk.3mf, Desk.step, Desk.stl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]
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2026-10-05 fix(cad): make space for USB port of ESP32
    [AiEmblem.3mf, AiEmblem.step, AiEmblem.stl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]
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2026-10-05 fix(cad): fix laptop screen sizing on smaller servo variants
    [LaptopCase.3mf, LaptopCase.step, LaptopCase.stl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]
2026-10-06 add extension port
    [main-control-board-esp32.kicad_sch, main-control-board.kicad_pcb, main-control-board.kicad_sch]
2026-10-06 update BOM
    [main-control-board.kicad_pcb, main-control-board.kicad_sch]
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2026-10-06 update silkscreen layer for main control board: add knockout effect to VCC and voltage labels
    [main-control-board.kicad_pcb]
2026-10-07 add ESP antenna keepout
    [main-control-board.kicad_pcb]
2026-10-07 add 100nF to U4 dVdt
    [main-control-board-pca.kicad_sch, main-control-board.kicad_pcb]
2026-10-07 add capacitor next to pin 28 of PCA
    [main-control-board-esp32.kicad_sch, main-control-board.kicad_pcb]
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2026-10-08 add EMAX ES 9051 spex
    [servos.json]
2026-10-08 fix(integrations): validate JSON format for hooks.json during setup and add corresponding test case
2026-10-10 fix(firmware): turn off green LED after wifi connect
    [main.cpp]
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2026-11-01 fix(firmware): update I2S configuration and tone generation parameters in PCBA tester
2026-11-05 feat(web): document web assembly (#101)
    * feat(scripts): extract assembled part placements from the Fusion design
    Read every occurrence's solved transform from 3d_models/cad/TinyEngineer.f3d
    (via ezf3d, no Fusion needed) and combine it with the PRINT_LAYOUT transform
    to take each exported STL from its print pose to its assembled pose. Servos,
    OLED and the main control board are tessellated from the design's own bodies.
    Every placement is checked against the exported SG90 STLs and the named
    joints; the run fails otherwise. build_glb.mjs packs the result into one GLB.
    CI job 'assembly' builds it and uploads it as an artifact.
    * feat(w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
2026-11-08 fix(ci): update caching key and refine environment setup for KiCad AppImage
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2026-11-09 feat(actions): implement on-device event-action bindings
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
